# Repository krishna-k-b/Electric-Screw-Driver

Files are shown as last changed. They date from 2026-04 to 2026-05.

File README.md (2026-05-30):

# Electric-Screw-Driver
Attempt to make a Torque-sensing DC screwdriver using motor current feedback for real-time torque estimation and inertia aware control

# DRV8701 + RP2040 Brushed DC Screwdriver

Firmware for a handheld brushed-DC screwdriver using a Raspberry Pi Pico (RP2040) and a DRV8701 gate driver in PH/EN mode with an external N-MOSFET H-bridge. Features closed-loop current sensing, configurable torque limiting, soft-start, dithering, and full serial telemetry over CMSIS-DAP / Picoprobe.

## Table of Contents

- [Hardware Overview](#hardware-overview)
- [Pin Map](#pin-map)
- [Current Sensing Circuit](#current-sensing-circuit)
- [Building](#building)
- [Flashing](#flashing)
- [Debug / Serial Interface](#debug--serial-interface)
- [Serial Commands](#serial-commands)
- [State Machine](#state-machine)
- [Torque Control](#torque-control)
- [LED Indicator](#led-indicator)
- [Configuration Reference](#configuration-reference)

---

## Hardware Overview

| Component | Part |
|---|---|
| MCU | Raspberry Pi Pico (RP2040) |
| Gate driver | Texas Instruments DRV8701 |
| Bridge topology | External N-MOSFET H-bridge (PH/EN mode) |
| Current sense | 5 mΩ shunt + DRV8701 SO pin + resistor divider |
| Trigger | Two momentary buttons — CW (GP13) and CCW (GP12) |
| Speed control | Fixed 100 % duty with soft-start ramp (no pot fitted) |

---

## Pin Map

| GPIO | Direction | Function |
|---|---|---|
| GP0 | OUT | UART0 TX → Picoprobe GP5 |
| GP1 | IN | UART0 RX → Picoprobe GP4 |
| GP12 | IN (pull-up) | Button CCW — active LOW |
| GP13 | IN (pull-up) | Button CW — active LOW |
| GP16 | OUT (PWM) | DRV8701 EN/PWM — 20 kHz |
| GP17 | OUT | DRV8701 PH/DIR — HIGH = CW |
| GP18 | OUT | DRV8701 nSLEEP — LOW = Hi-Z |
| GP19 | IN (pull-up) | DRV8701 nFAULT — open-drain active LOW |
| GP26 | AIN | ADC CH0 — SO current sense |
| GP27 | AIN | ADC CH1 — pot (wired, reading disabled) |
| GP25 | OUT | Onboard LED |

---

## Current Sensing Circuit

The DRV8701 SO pin outputs a voltage proportional to motor current. A resistor divider scales it to the RP2040's 3.3 V ADC range.

```
SO pin ──┬── 10 kΩ ──── 3.3 V
         │
         ├── GP26 (ADC CH0)
         │
        20 kΩ
         │
        GND
```

| Parameter | Value |
|---|---|
| Divider ratio (V_ADC / V_SO) | 0.6667 (20 / 30) |
| Amplifier gain | 20 V/V |
| Sense resistor | 5 mΩ |
| SO offset voltage | 50 mV |

**Current calculation** (per loop tick):

```
V_SO_real      = V_ADC / 0.6667
V_SO_on_phase  = V_SO_real / duty_fraction      ← duty-cycle compensation
V_across_amp   = V_SO_on_phase − 0.050 V
I              = V_across_amp / (20 × 0.005)
```

Readings are frozen when duty < 10 % to avoid noise during near-zero on-time. A first-order IIR filter (α = 0.25) smooths the result.

---

## Building

### Prerequisites

- [Raspberry Pi Pico SDK](https://github.com/raspberrypi/pico-sdk) (≥ 1.5)
- CMake ≥ 3.13
- `arm-none-eabi-gcc`

### CMakeLists.txt fragment

```cmake
add_executable(screwdriver DRV_ESD.cpp)

target_link_libraries(screwdriver PRIVATE
    pico_stdlib
    hardware_pwm
    hardware_adc
    hardware_gpio
    hardware_uart
    hardware_watchdog
    hardware_clocks
)

pico_enable_stdio_uart(screwdriver 1)
pico_enable_stdio_usb(screwdriver 0)
pico_add_extra_outputs(screwdriver)
```

### Build

```bash
mkdir build && cd build
cmake ..
make -j4
```

This produces `DRV_ESD.uf2`.

---

## Flashing

Hold the **BOOTSEL** button on the Pico while plugging in USB. Drag `DRV_ESD.uf2` onto the `RPI-RP2` mass-storage device that appears. The board resets and starts running immediately.
Above is for flashing without debugger, i usually flash the .elf file through debugger. Read Pico Debug documentation should you wish to flash using a debugger.

---

## Debug / Serial Interface

Connect a second Pico running [Picoprobe](https://github.com/raspberrypi/picoprobe) firmware:

| Target | Picoprobe |
|---|---|
| GP0 (TX) | GP5 |
| GP1 (RX) | GP4 |
| GND | GND |

Open the CDC serial port at **921 600 baud, 8N1**. All log lines are prefixed with a millisecond timestamp:

```
[T+   1234 ms] STATE  IDLE -> STARTING  [trigger engaged]
[T+   1284 ms] TELEM  STARTING  dir=CW   I= 0.12A ...
```

---

## Serial Commands

Send commands surrounded by angle brackets, e.g. `<help>`.

| Command | Description |
|---|---|
| `<help>` | Full status dump + command list |
| `<status>` | Same as `<help>` |
| `<cw>` | Start motor CW (latched until `<stop>` or torque trip) |
| `<ccw>` | Start motor CCW (latched until `<stop>` or torque trip) |
| `<stop>` | Clear any serial motor request |
| `<ith X.X>` | Set current threshold in amps, e.g. `<ith 4.5>` |

Serial requests behave identically to physical button presses. `<cw>` and `<ccw>` are only accepted from **IDLE** or **STOPPED**; they are ignored and logged otherwise.

---

## State Machine

```
         ┌──────────────────────────────────────────────────────────────────┐
         │  nFAULT asserted (any time)                                      ▼
  BOOT ──► IDLE ──trigger──► STARTING ──ramp done──► RUNNING               FAULT
           ▲                    │                      │  │                   │
           │              early release             trip │  I > 80% Ith       │ nFAULT clear
           │                    │                        ▼  ▼              + holdoff
           │                    └───────────────► STOPPING ◄── DITHERING      │
           │                                          │             │          │
           │                                    cooldown done       │ I < 60% Ith
           │                                          ▼             │
           └──────────────── trigger released ── STOPPED            └──► RUNNING
```

| State | Description |
|---|---|
| `BOOT` | One-shot init, transitions immediately to `IDLE` |
| `IDLE` | Waiting for trigger; bridge is in sleep / Hi-Z |
| `STARTING` | 200 ms linear duty ramp from 0 → 100 % |
| `RUNNING` | Full duty, monitoring current |
| `DITHERING` | Near threshold — duty modulated to hold current just below limit |
| `STOPPING` | EN = 0 (brake), 300 ms cooldown before sleep |
| `STOPPED` | Bridge asleep; waiting for trigger release before next run |
| `FAULT` | nFAULT asserted by DRV8701; motor braked, LED solid ON |

**Trigger logic** — either the physical button *or* a latched serial request counts as a trigger. If both CW and CCW are simultaneously active (buttons or serial), no motion occurs until the conflict resolves.

---

## Torque Control

Three layered mechanisms protect the motor and workpiece:

### 1. Threshold current trip (sustained overcurrent)

The firmware trips if `I_filtered ≥ I_threshold` persists for **5 consecutive milliseconds**. Default threshold is **5.0 A**; adjustable at runtime with `<ith X.X>` (range 2–10 A). On trip, the motor brakes and the state machine enters `STOPPING`.

### 2. Hard limit

If filtered current reaches **14 A** at any time — including during soft-start — the motor brakes immediately regardless of threshold setting. This protects the FETs from thermal runaway.

### 3. Rapid dI/dt (stall detection)

A ring buffer of the last 8 current samples is compared oldest-to-newest. If the window rise exceeds **4 A**, the motor trips. This catches stalls that happen before sustained overcurrent would fire.

### Dithering (soft current limiting)

Between **80 %** and **100 %** of the threshold current the firmware enters `DITHERING` and scales the duty cycle proportionally down to a minimum of **30 %**, holding torque steady rather than hard-tripping. The motor returns to `RUNNING` if current drops back below **60 %** of threshold.

---

## LED Indicator

| LED state | Meaning |
|---|---|
| Off | Idle / stopped / boot |
| Blinking (0.5 s period) | Motor energised (STARTING, RUNNING, DITHERING) |
| Solid ON | FAULT |

---

## Configuration Reference

All compile-time tunables are `constexpr` near the top of `DRV_ESD.cpp`.

| Symbol | Default | Description |
|---|---|---|
| `I_THRESHOLD_DEFAULT_A` | 5.0 A | Starting current threshold (no pot) |
| `I_THRESHOLD_MIN_A` | 2.0 A | Lower bound for `<ith>` command |
| `I_THRESHOLD_MAX_A` | 10.0 A | Upper bound for `<ith>` command |
| `I_HARD_LIMIT_A` | 14.0 A | Unconditional FET protection limit |
| `SOFT_START_MS` | 200 ms | Duty ramp duration on trigger press |
| `COOLDOWN_MS` | 300 ms | Brake hold time before bridge sleeps |
| `FAULT_HOLDOFF_MS` | 150 ms | Debounce after nFAULT clears |
| `OVERCURRENT_CONFIRM_MS` | 5 ms | Sustained OC window before trip |
| `DI_DT_TRIP_A_PER_WIN` | 4.0 A | dI/dt trip threshold over 8-sample window |
| `DITHER_START_FRAC` | 0.80 | Dither zone entry — fraction of I_threshold |
| `DITHER_MIN_DUTY_FRAC` | 0.30 | Minimum PWM duty while dithering |
| `IIR_ALPHA` | 0.25 | Current filter coefficient (higher = faster) |
| `PWM_WRAP` | 6249 | PWM counter wrap → 20 kHz at 125 MHz |
| `LOOP_PERIOD_US` | 5000 µs | Main loop period (200 Hz) |
| `WATCHDOG_TIMEOUT_MS` | 250 ms | Watchdog reset if loop stalls |
| `UART_BAUD` | 921 600 | Debug UART baud rate |

---

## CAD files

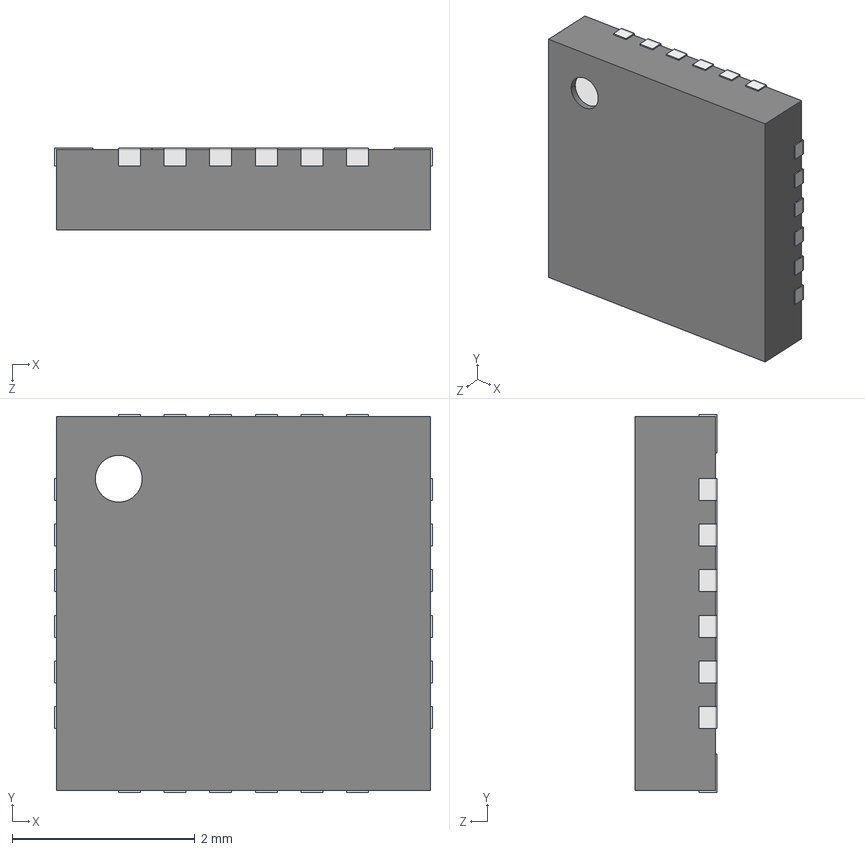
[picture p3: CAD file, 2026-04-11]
DRV8701-ESD_PCB/ul_DRV8701ERGER/qfn-24-1.snapshot.1/QFN 24.STEP
4.14 x 4.14 x 0.9 mm
Open_CASCADE_STEP_translator_6.8_11.2.1.step_Varsay考an
Open_CASCADE_STEP_translator_6.8_11.4.1.step_Varsay考an x 24
Open_CASCADE_STEP_translator_6.8_11.1.step_Varsay考an
Thermal_Shape.step_Varsay考an

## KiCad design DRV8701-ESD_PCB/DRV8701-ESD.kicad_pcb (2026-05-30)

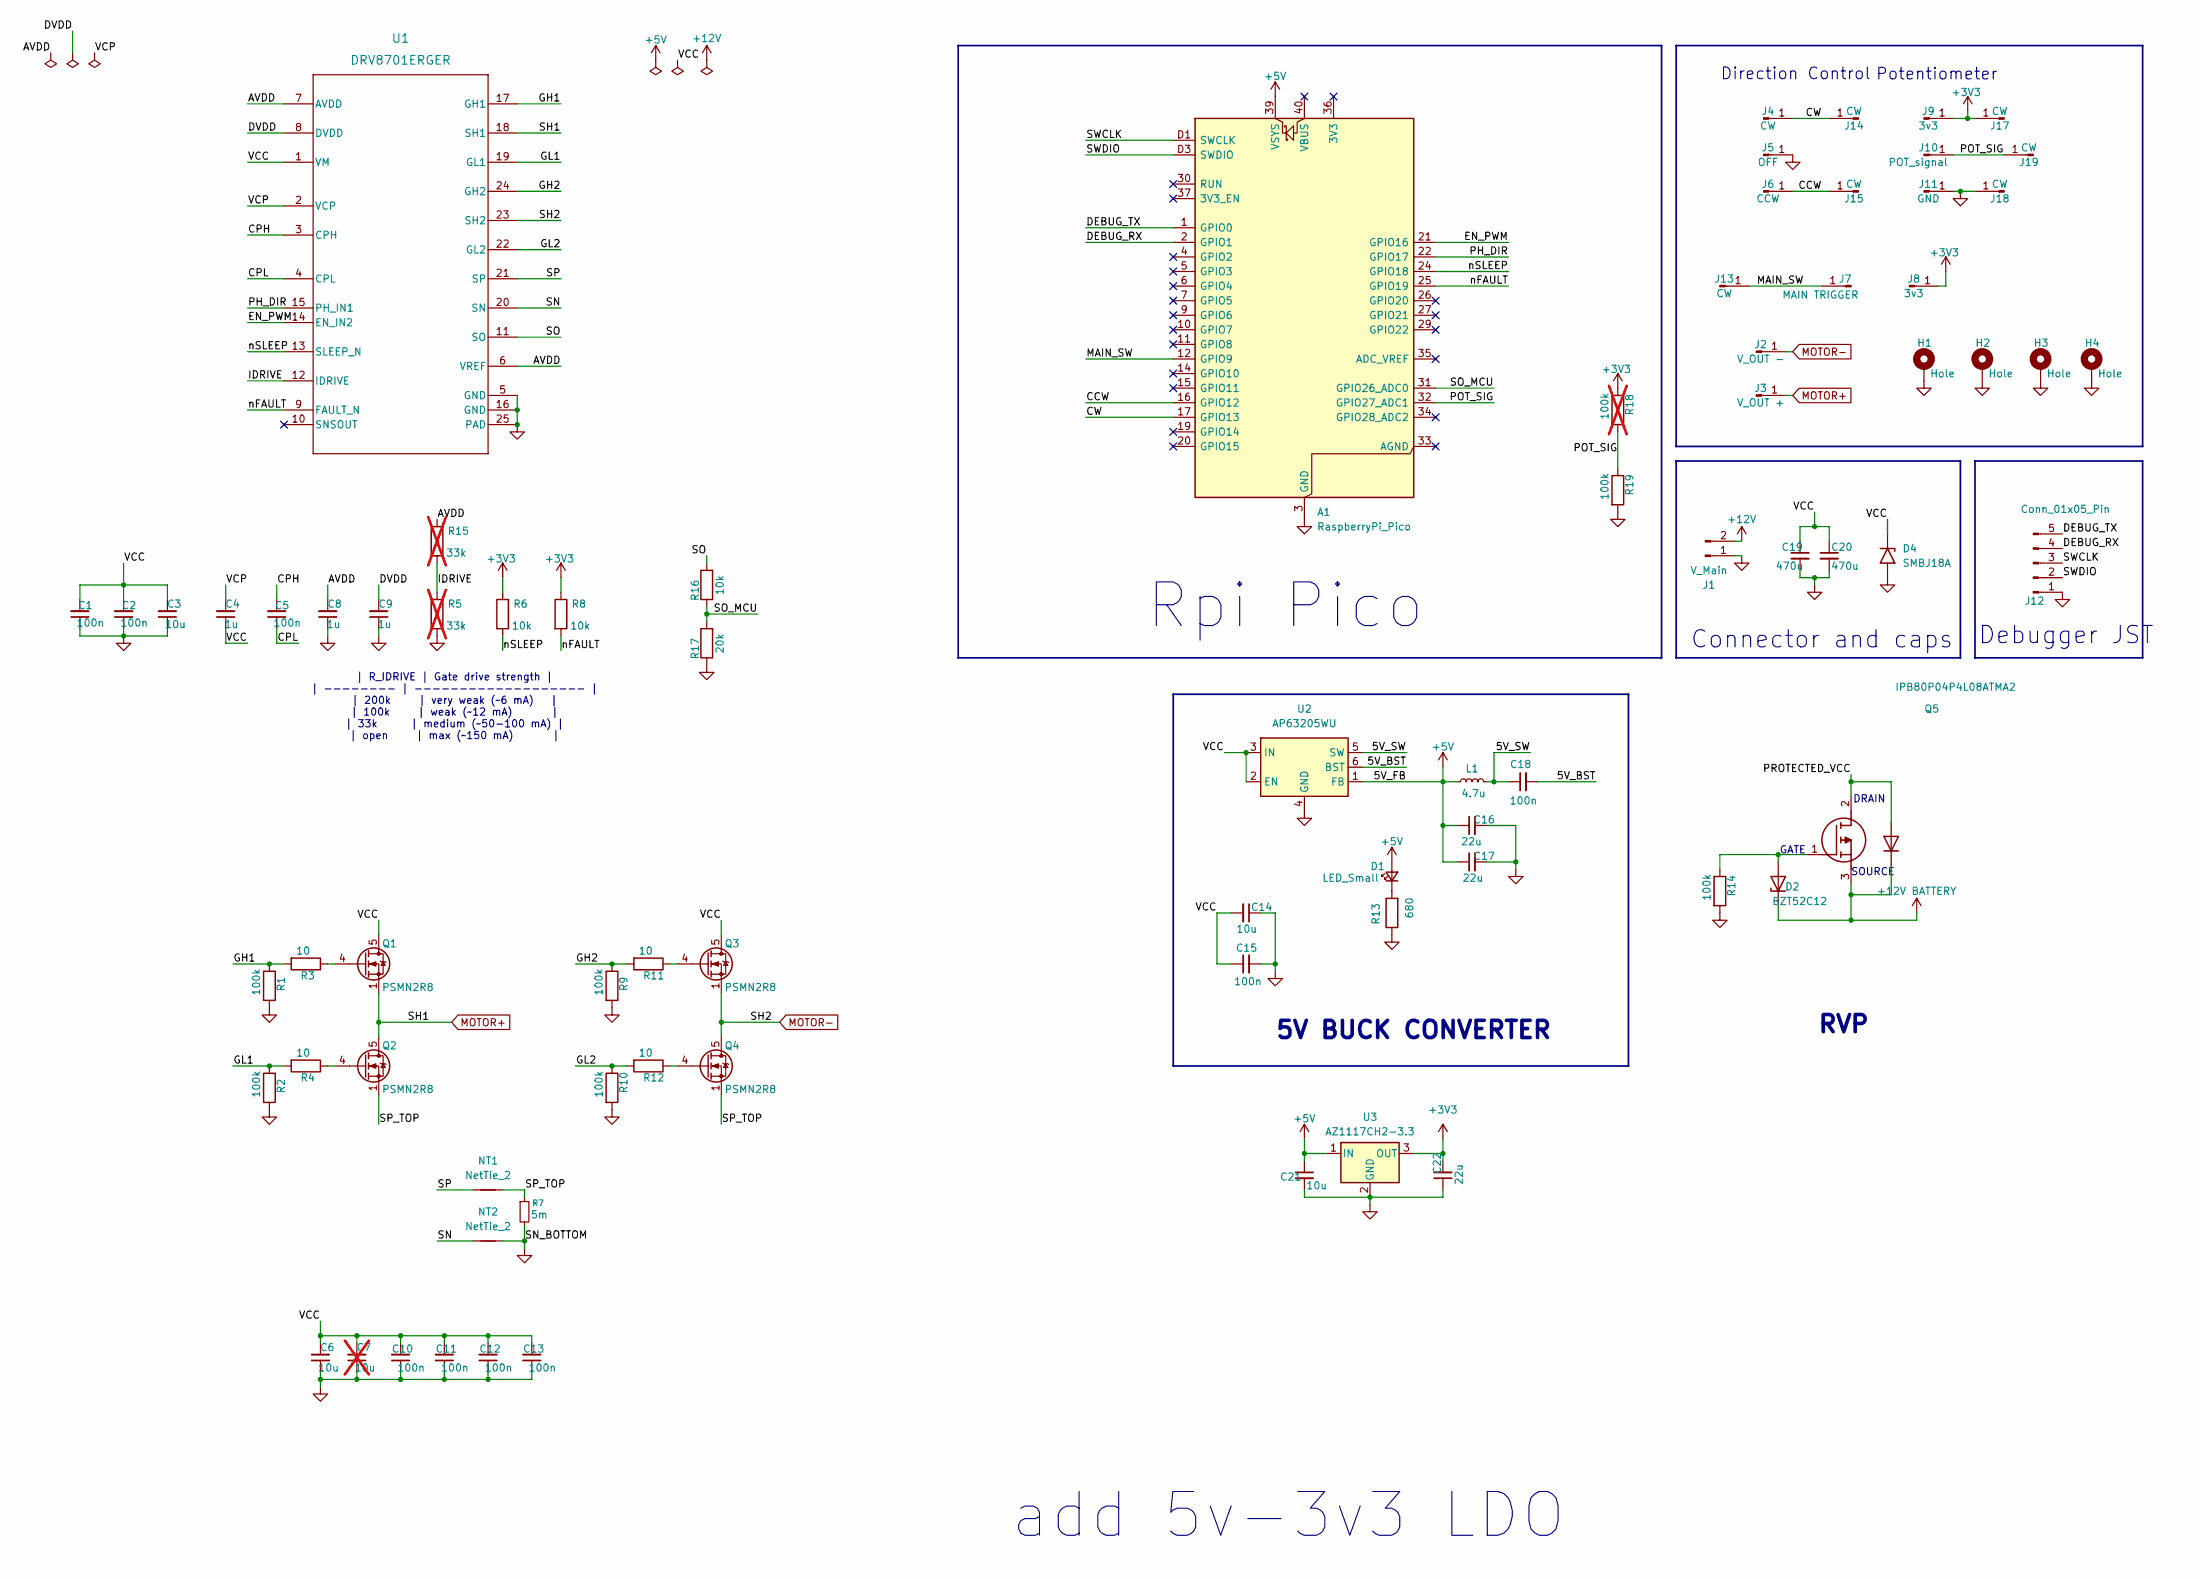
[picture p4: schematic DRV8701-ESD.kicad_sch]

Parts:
A1: RaspberryPi_Pico; RaspberryPi_Pico_SMD_HandSolder
C1, C2, C5, C10, C11, C12, C13, C15, C18: 100n; C_0603_1608Metric_Pad1.08x0.95mm_HandSolder
C3, C6, C14, C21: 10u; C_1206_3216Metric_Pad1.33x1.80mm_HandSolder; LCSC C77096
C4, C8, C9: 1u; C_0805_2012Metric_Pad1.18x1.45mm_HandSolder
C7: 10u; C_1206_3216Metric_Pad1.33x1.80mm_HandSolder; LCSC C77096; not fitted
C16, C17, C22: 22u; C_1210_3225Metric_Pad1.33x2.70mm_HandSolder; LCSC C86816
C19, C20: 470u; C_Radial_D10.0mm_H20.0mm_P5.00mm
D1: LED_Small; LED_0603_1608Metric_Pad1.05x0.95mm_HandSolder
D2: BZT52C12; D_SOD-123F
D4: SMBJ18A; D_SMA-SMB_Universal_Handsoldering
H1, H2, H3, H4: Hole; MountingHole_3.2mm_M3_Pad
J1: V_Main; AMASS_XT60-F_1x02_P7.20mm_Vertical
J2: V_OUT -; Solder_Pad_10x10mm_withVias
J3: V_OUT +; Solder_Pad_10x10mm_withVias
J4: CW; PinHeader_1x01_P2.54mm_Vertical
J5: OFF; PinHeader_1x01_P2.54mm_Vertical
J6: CCW; PinHeader_1x01_P2.54mm_Vertical
J7: MAIN TRIGGER; PinHeader_1x01_P2.54mm_Vertical
J8, J9: 3v3; PinHeader_1x01_P2.54mm_Vertical
J10: POT_signal; PinHeader_1x01_P2.54mm_Vertical
J11: GND; PinHeader_1x01_P2.54mm_Vertical
J12: Conn_01x05_Pin; Molex_PicoBlade_53047-0510_1x05_P1.25mm_Vertical
J13, J14, J15, J17, J18, J19: CW; 3.5x3.5_Solder_Pads
L1: 4.7u; L_SMD_6mmx6mm
NT1, NT2: NetTie_2; NetTie-2_SMD_Pad0.2mm
Q1, Q2, Q3, Q4: PSMN2R8; LFPAK56
Q5: IPB80P04P4L08ATMA2; TO-263-2
R1, R2, R9, R10, R14, R19: 100k; R_0603_1608Metric_Pad0.98x0.95mm_HandSolder
R3, R4, R11, R12: 10; R_0603_1608Metric_Pad0.98x0.95mm_HandSolder
R5, R15: 33k; R_0603_1608Metric_Pad0.98x0.95mm_HandSolder; not fitted
R6, R8, R16: 10k; R_0603_1608Metric_Pad0.98x0.95mm_HandSolder
R7: 5m; R_2512_6332Metric_Pad1.40x3.35mm_HandSolder
R13: 680; C_0603_1608Metric_Pad1.08x0.95mm_HandSolder
R17: 20k; R_0603_1608Metric_Pad0.98x0.95mm_HandSolder
R18: 100k; R_0603_1608Metric_Pad0.98x0.95mm_HandSolder; not fitted
U1: DRV8701ERGER; RGE0024F_NV
U2: AP63205WU; TSOT-23-6
U3: AZ1117CH2-3.3; SOT-223-3_TabPin2

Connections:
+3V3: C22.2, J8.1, J9.1, J17.1, R6.1, R8.1, R18.1, U3.3 (OUT)
+5V: A1.39 (VSYS), C16.1, C17.1, C21.1, D1.2 (A), L1.1, U2.1 (FB), U3.1 (IN)
/5V_BST: C18.2, U2.6 (BST)
/5V_SW: C18.1, L1.2, U2.5 (SW)
/AVDD: C8.2, R15.1, U1.6 (VREF), U1.7 (AVDD)
/CCW: A1.16 (GPIO12), J6.1, J15.1
/CPH: C5.2, U1.3 (CPH)
/CPL: C5.1, U1.4 (CPL)
/CW: A1.17 (GPIO13), J4.1, J14.1
/DEBUG_RX: A1.2 (GPIO1), J12.4
/DEBUG_TX: A1.1 (GPIO0), J12.5
/DVDD: C9.2, U1.8 (DVDD)
/EN_PWM: A1.21 (GPIO16), U1.14 (EN_IN2)
/GH1: R1.1, R3.2, U1.17 (GH1)
/GH2: R9.1, R11.2, U1.24 (GH2)
/GL1: R2.1, R4.2, U1.19 (GL1)
/GL2: R10.1, R12.2, U1.22 (GL2)
/IDRIVE: R5.1, R15.2, U1.12 (IDRIVE)
/MAIN_SW: A1.12 (GPIO9), J7.1, J13.1
/PH_DIR: A1.22 (GPIO17), U1.15 (PH_IN1)
/POT_SIG: A1.32 (GPIO27_ADC1), J10.1, J19.1, R18.2, R19.1
/SN: NT2.1, U1.20 (SN)
/SO: R16.2, U1.11 (SO)
/SO_MCU: A1.31 (GPIO26_ADC0), R16.1, R17.2
/SP: NT1.1, U1.21 (SP)
/SP_TOP: NT1.2, Q2.1 (S), Q2.2 (S), Q2.3 (S), Q4.1 (S), Q4.2 (S), Q4.3 (S), R7.1
/SWCLK: A1.D1 (SWCLK), J12.3
/SWDIO: A1.D3 (SWDIO), J12.2
/VCP: C4.2, U1.2 (VCP)
/nFAULT: A1.25 (GPIO19), R8.2, U1.9 (FAULT_N)
/nSLEEP: A1.24 (GPIO18), R6.2, U1.13 (SLEEP_N)
GND: A1.3 (GND), A1.8 (GND), A1.13 (GND), A1.18 (GND), A1.23 (GND), A1.28 (GND), A1.38 (GND), A1.D2 (GND), C1.1, C2.1, C3.1, C6.1, C7.1, C8.1, C9.1, C10.1, C11.1, C12.1, C13.1, C14.1, C15.2, C16.2, C17.2, C19.2, C20.2, C21.2, C22.1, D4.2 (A2), H1.1, H2.1, H3.1, H4.1, J1.1, J5.1, J11.1, J12.1, J18.1, NT2.2, R1.2, R2.2, R5.2, R7.2, R9.2, R10.2, R13.1, R14.2, R17.1, R19.2, U1.5 (GND), U1.16 (GND), U1.25 (PAD), U2.4 (GND), U3.2 (GND)
MOTOR+: J3.1, Q1.1 (S), Q1.2 (S), Q1.3 (S), Q2.5 (D), U1.18 (SH1)
MOTOR-: J2.1, Q3.1 (S), Q3.2 (S), Q3.3 (S), Q4.5 (D), U1.23 (SH2)
unnamed: D1.1 (K), R13.2
unnamed: D2.2 (A), Q5.1 (G), R14.1
unnamed: Q1.4 (G), R3.1
unnamed: Q2.4 (G), R4.1
unnamed: Q3.4 (G), R11.1
unnamed: Q4.4 (G), R12.1

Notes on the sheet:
Potentiometer
5V BUCK CONVERTER
Debugger JST
DRAIN
Direction Control
GATE
| R_IDRIVE | Gate drive strength | | -------- | ------------------- | | 200k | very weak (~6 mA) | | 100k | weak (~12 mA) | | 33k | medium (~50-100 mA) | | open | max (~150 mA) |
SOURCE
add 5v-3v3 LDO
Rpi Pico
RVP
Connector and caps

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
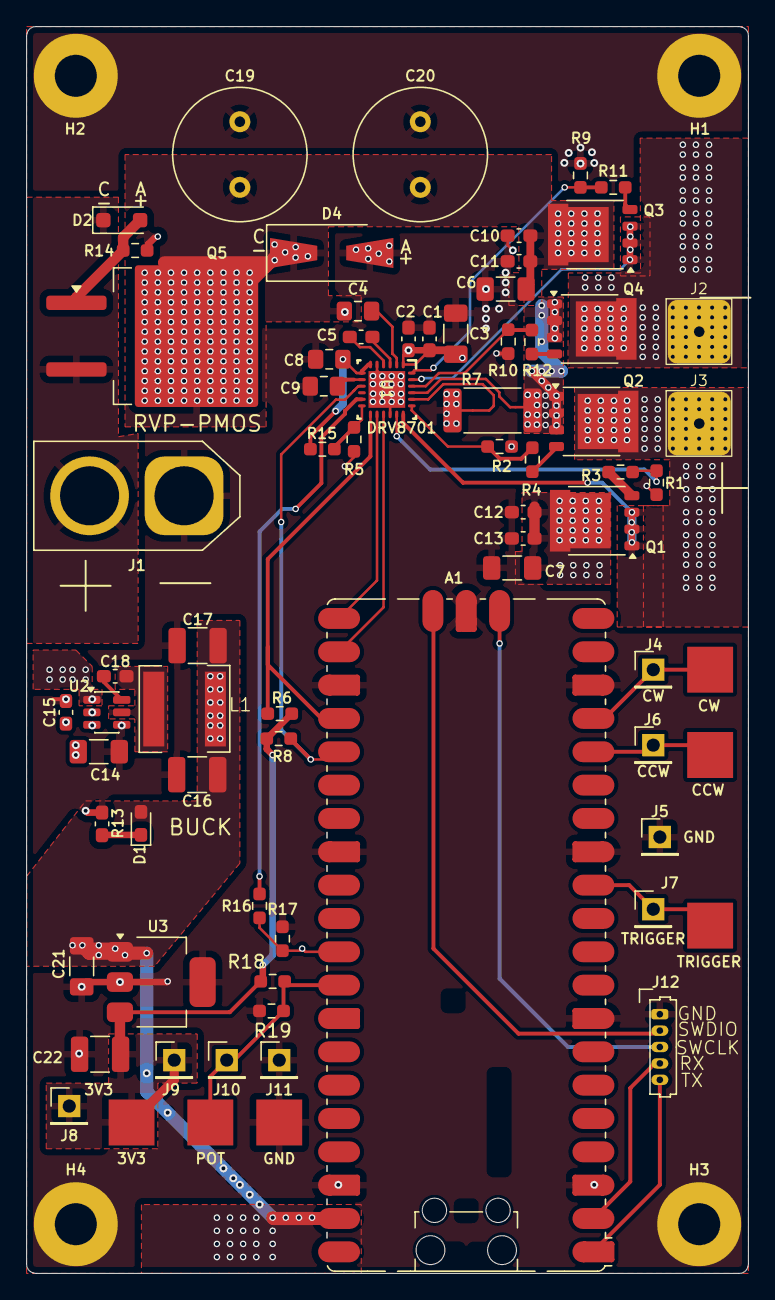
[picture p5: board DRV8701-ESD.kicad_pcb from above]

Board: 4 copper layers, 55.0 x 95.0 mm, 78 parts (0 on the bottom side), 42 nets.

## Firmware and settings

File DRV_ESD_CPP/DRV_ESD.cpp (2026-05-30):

/* =========================================================================
 *  DRV8701 + RP2040 Brushed DC Screwdriver Firmware
 *  -------------------------------------------------
 *  Toolchain : Pico SDK (C/C++), no Arduino libraries.
 *  MCU       : Raspberry Pi Pico (RP2040)
 *  Driver    : DRV8701 in PH/EN mode with external N-MOSFET H-bridge
 *
 *  CMSIS-DAP / Picoprobe serial debug
 *  ------------------------------------
 *  Connect a second Pico running Picoprobe firmware:
 *    Target GP0 (TX) -> Picoprobe GP5
 *    Target GP1 (RX) -> Picoprobe GP4
 *  Open the CDC serial port at 115200 baud in your IDE / terminal.
 *  All events are timestamped [T+xxxxx ms].
 *
 *  SO divider: 10 k (top) + 20 k (bottom)
 *    V_adc = V_SO * 20/(10+20) = 0.6667  =>  SO_DIVIDER_RATIO = 0.6667
 *
 *  TRIGGER LOGIC (no separate trigger button):
 *    - CW  button (GP13, active-LOW, internal pull-up) = run CW  while held
 *    - CCW button (GP12, active-LOW, internal pull-up) = run CCW while held
 *    - Both pressed simultaneously => no motion
 *    - Motor also controllable via serial commands (see <help>)
 *
 *  POT: not connected. Threshold defaults to I_THRESHOLD_DEFAULT_A.
 *       Use <ith X.X> serial command to change at runtime.
 *
 *  LED (GP25 onboard):
 *    OFF   = idle / stopped / boot
 *    BLINK = motor energised (STARTING / RUNNING / DITHERING) - 0.5 s period
 *    ON    = FAULT state
 *
 *  Serial commands  (send inside angle brackets, e.g.  <help> ):
 *    <help>      full status dump + command list
 *    <status>    same as <help>
 *    <cw>        start motor CW  (latched until <stop> or trip)
 *    <ccw>       start motor CCW (latched until <stop> or trip)
 *    <stop>      release serial motor request
 *    <ith X.X>   set current threshold in amps  (e.g. <ith 4.5>)
 *
 *  Build (CMakeLists.txt fragment)
 *    add_executable(screwdriver screwdriver_firmware.cpp)
 *    target_link_libraries(screwdriver PRIVATE
 *        pico_stdlib hardware_pwm hardware_adc hardware_gpio
 *        hardware_uart hardware_watchdog hardware_clocks)
 *    pico_enable_stdio_uart(screwdriver 1)
 *    pico_enable_stdio_usb(screwdriver 0)
 *    pico_add_extra_outputs(screwdriver)
 * ========================================================================= */

#include "hardware/adc.h"
#include "hardware/clocks.h"
#include "hardware/gpio.h"
#include "hardware/pwm.h"
#include "hardware/uart.h"
#include "hardware/watchdog.h"
#include "pico/stdlib.h"
#include "pico/time.h"
#include <cmath>
#include <cstdint>
#include <cstdio>
#include <cstring>
#include <stdio.h>
#include <string.h>

/* =========================================================================
 *  CONFIG -- adjust to match your hardware
 * ========================================================================= */

/* ---- Pin map ---- */
static constexpr uint PIN_UART_TX = 0;
static constexpr uint PIN_UART_RX = 1;
/* GP9 (main trigger) intentionally unused -- CW/CCW are the triggers */
static constexpr uint PIN_BTN_CCW = 12;
static constexpr uint PIN_BTN_CW  = 13;
static constexpr uint PIN_EN_PWM  = 16;
static constexpr uint PIN_PH_DIR  = 17;
static constexpr uint PIN_NSLEEP  = 18;
static constexpr uint PIN_NFAULT  = 19;
static constexpr uint PIN_ADC_SO  = 26;
static constexpr uint PIN_ADC_POT = 27; /* wired but reading ignored (POT_CONNECTED=false) */
static constexpr uint ADC_CH_SO   = 0;
static constexpr uint ADC_CH_POT  = 1;
static constexpr uint PIN_LED     = 25; /* onboard LED */

/* ---- Button polarity ---- */
static constexpr int BTN_PRESSED = 0; /* active-LOW with pull-up */

/* ---- Pot / threshold ---- */
static constexpr bool  POT_CONNECTED          = false;
static constexpr float I_THRESHOLD_DEFAULT_A  = 5.0f; /* used when POT_CONNECTED=false */

/* ---- Analog ---- */
static constexpr float ADC_VREF_V       = 3.3f;
static constexpr float ADC_COUNTS       = 4096.0f;
static constexpr float SO_DIVIDER_RATIO = 0.6667f; /* 10k top + 20k bottom */
static constexpr float DRV_AMP_GAIN     = 20.0f;  /* V/V */
static constexpr float R_SENSE_OHM      = 0.005f; /* 5 mohm */
static constexpr float SO_OFFSET_V      = 0.050f; /* V_OFF typical (DS tbl 6.5) */

/* ---- PWM ---- */
/* 125 MHz / (1 * 6250) = 20 kHz */
static constexpr uint16_t PWM_WRAP    = 6249;
static constexpr float    PWM_CLKDIV  = 1.0f;
static constexpr uint16_t PWM_DUTY_MAX = PWM_WRAP;

/* ---- Torque limits ---- */
static constexpr float I_THRESHOLD_MIN_A  = 2.0f;
static constexpr float I_THRESHOLD_MAX_A  = 10.0f;
static constexpr float I_HARD_LIMIT_A     = 14.0f;
static constexpr float DUTY_FLOOR_FOR_I_EST = 0.10f;

/* ---- Timing ---- */
static constexpr uint32_t LOOP_PERIOD_US      = 5000;
static constexpr uint32_t SOFT_START_MS       = 200;
static constexpr uint32_t COOLDOWN_MS         = 300;
static constexpr uint32_t DEBOUNCE_MS         = 25;
static constexpr uint32_t FAULT_HOLDOFF_MS    = 150;
static constexpr uint32_t WAKE_DELAY_MS       = 2;
static constexpr uint32_t WATCHDOG_TIMEOUT_MS = 250;

/* ---- Logging ---- */
static constexpr uint32_t LOG_PERIOD_ACTIVE_MS = 50;  /* 20 Hz while running */
static constexpr uint32_t LOG_PERIOD_IDLE_MS   = 500; /* 2 Hz at idle/stopped */

/* ---- LED ---- */
static constexpr uint32_t LED_BLINK_HALF_MS = 250; /* on 250ms, off 250ms => 0.5s period */

/* ---- Filtering & detection ---- */
static constexpr float IIR_ALPHA            = 0.25f;
static constexpr int   DI_DT_HISTORY        = 8;
static constexpr float DI_DT_TRIP_A_PER_WIN = 4.0f;
static constexpr float DITHER_START_FRAC    = 0.80f;
static constexpr float DITHER_MIN_DUTY_FRAC = 0.30f;
static constexpr int   OVERCURRENT_CONFIRM_MS = 5;

/* ---- UART ---- */
static constexpr uint32_t UART_BAUD = 921600
;
#define UART_ID uart0

/* =========================================================================
 *  TYPES
 * ========================================================================= */

enum class State : uint8_t {
  BOOT,
  IDLE,
  STARTING,
  RUNNING,
  DITHERING,
  STOPPING,
  STOPPED,
  FAULT
};

enum class Direction : uint8_t { CW = 1, CCW = 0 };

struct Button {
  uint  pin;
  bool  stable;
  bool  last_raw;
  absolute_time_t last_change;
  bool  edge_pressed;
  bool  edge_released;
};

struct Context {
  State     state;
  Direction dir;
  uint      pwm_slice;
  uint      pwm_chan;

  Button sw_cw;
  Button sw_ccw;

  /* Serial virtual buttons (latched by <cw>/<ccw>, cleared by <stop>/trip) */
  bool serial_cw_req;
  bool serial_ccw_req;

  /* Conflict tracking (both buttons simultaneously) */
  bool conflict_logged;

  /* Analog */
  float i_filt_a;
  float i_raw_a;
  float i_threshold_a; /* set from pot (if connected) or serial <ith> command */
  float pot_v;
  float so_v;
  float duty_frac;

  /* dI/dt history */
  float i_hist[DI_DT_HISTORY];
  int   i_hist_idx;
  float di_dt_last;

  /* Trip confirmations */
  int overcurrent_ms;
  int fault_holdoff_ms;

  /* PWM control */
  uint16_t duty_target;
  uint16_t duty_current;
  absolute_time_t soft_start_began;

  /* Cooldown */
  absolute_time_t cooldown_began;

  /* Logging */
  absolute_time_t last_log;
  absolute_time_t boot_time;
  uint16_t        last_logged_duty;

  /* Hardware state tracking (avoid repeated log spam) */
  bool nsleep_out;  /* current logical state of nSLEEP pin */

  /* Fault */
  bool        nfault_asserted;
  const char *fault_reason;

  /* Serial command buffer */
  char serial_buf[80];
  int  serial_buf_len;
  bool serial_in_cmd;
};

static Context g{};

/* =========================================================================
 *  TIMESTAMP + LOG MACRO
 * ========================================================================= */

static uint32_t ts_ms(void) {
  return (uint32_t)(absolute_time_diff_us(g.boot_time, get_absolute_time()) /
                    1000);
}

#define LOG(fmt, ...) printf("[T+%7u ms] " fmt "\n", ts_ms(), ##__VA_ARGS__)

/* =========================================================================
 *  LOW-LEVEL HELPERS
 * ========================================================================= */

static inline float clampf(float v, float lo, float hi) {
  return v < lo ? lo : (v > hi ? hi : v);
}

/* =========================================================================
 *  TRIGGER LOGIC
 *  Returns true if the currently active direction's trigger is still held.
 *  Physical button OR latched serial request counts.
 * ========================================================================= */

static bool want_cw(void)  { return g.sw_cw.stable  || g.serial_cw_req;  }
static bool want_ccw(void) { return g.sw_ccw.stable  || g.serial_ccw_req; }

static bool trigger_held(void) {
  if (g.dir == Direction::CW)  return want_cw();
  if (g.dir == Direction::CCW) return want_ccw();
  return false;
}

/* =========================================================================
 *  PERIPHERAL INIT
 * ========================================================================= */

static void uart_init_debug(void) {
  uart_init(UART_ID, UART_BAUD);
  gpio_set_function(PIN_UART_TX, GPIO_FUNC_UART);
  gpio_set_function(PIN_UART_RX, GPIO_FUNC_UART);
  uart_set_format(UART_ID, 8, 1, UART_PARITY_NONE);
  uart_set_fifo_enabled(UART_ID, true);
  stdio_init_all();
}

static void gpio_init_all(void) {
  /* nSLEEP -- output, force LOW (sleep / Hi-Z) before we are ready */
  gpio_init(PIN_NSLEEP);
  gpio_put(PIN_NSLEEP, 0);
  gpio_set_dir(PIN_NSLEEP, GPIO_OUT);
  g.nsleep_out = false;

  /* PH direction -- output, default CW (HIGH) */
  gpio_init(PIN_PH_DIR);
  gpio_put(PIN_PH_DIR, 1);
  gpio_set_dir(PIN_PH_DIR, GPIO_OUT);

  /* nFAULT -- input with internal + external pull-up */
  gpio_init(PIN_NFAULT);
  gpio_set_dir(PIN_NFAULT, GPIO_IN);
  gpio_pull_up(PIN_NFAULT);

  /* CW / CCW buttons -- input, internal pull-up, active-LOW */
  const uint btns[] = {PIN_BTN_CW, PIN_BTN_CCW};
  for (uint p : btns) {
    gpio_init(p);
    gpio_set_dir(p, GPIO_IN);
    gpio_pull_up(p);
  }

  /* Onboard LED */
  gpio_init(PIN_LED);
  gpio_set_dir(PIN_LED, GPIO_OUT);
  gpio_put(PIN_LED, 0);
}

static void pwm_init_motor(void) {
  gpio_set_function(PIN_EN_PWM, GPIO_FUNC_PWM);
  g.pwm_slice = pwm_gpio_to_slice_num(PIN_EN_PWM);
  g.pwm_chan  = pwm_gpio_to_channel(PIN_EN_PWM);

  pwm_config cfg = pwm_get_default_config();
  pwm_config_set_wrap(&cfg, PWM_WRAP);
  pwm_config_set_clkdiv(&cfg, PWM_CLKDIV);
  pwm_init(g.pwm_slice, &cfg, false);

  pwm_set_chan_level(g.pwm_slice, g.pwm_chan, 0);
  pwm_set_enabled(g.pwm_slice, true);
}

static void adc_init_all(void) {
  adc_init();
  adc_gpio_init(PIN_ADC_SO);
  adc_gpio_init(PIN_ADC_POT);
}

/* =========================================================================
 *  ADC + CONVERSION
 * ========================================================================= */

static uint16_t adc_read_channel(uint ch) {
  adc_select_input(ch);
  uint32_t sum = 0;
  for (int i = 0; i < 4; ++i)
    sum += adc_read();
  return (uint16_t)(sum / 4);
}

static float adc_to_volts(uint16_t counts) {
  return ((float)counts / ADC_COUNTS) * ADC_VREF_V;
}

static float volts_to_current_a(float v_so_avg, float duty_frac) {
  if (duty_frac < DUTY_FLOOR_FOR_I_EST)
    return g.i_filt_a; /* freeze below floor duty */
  float v_so_real      = v_so_avg / SO_DIVIDER_RATIO;
  float v_so_during_on = v_so_real / duty_frac;
  float v_across_amp   = v_so_during_on - SO_OFFSET_V;
  if (v_across_amp < 0)
    v_across_amp = 0;
  return v_across_amp / (DRV_AMP_GAIN * R_SENSE_OHM);
}

static float pot_to_threshold_a(float v_pot) {
  float frac = clampf(v_pot / ADC_VREF_V, 0.0f, 1.0f);
  return I_THRESHOLD_MIN_A + frac * (I_THRESHOLD_MAX_A - I_THRESHOLD_MIN_A);
}

/* =========================================================================
 *  BUTTONS (debounced, edge detection)
 * ========================================================================= */

static void button_init(Button &b, uint pin) {
  b.pin           = pin;
  b.stable        = false;
  b.last_raw      = (gpio_get(pin) == BTN_PRESSED);
  b.last_change   = get_absolute_time();
  b.edge_pressed  = false;
  b.edge_released = false;
}

static void button_update(Button &b) {
  bool raw = (gpio_get(b.pin) == BTN_PRESSED);
  absolute_time_t now = get_absolute_time();

  if (raw != b.last_raw) {
    b.last_raw    = raw;
    b.last_change = now;
  }

  bool old_stable = b.stable;
  if (absolute_time_diff_us(b.last_change, now) >= (int64_t)DEBOUNCE_MS * 1000)
    b.stable = raw;

  b.edge_pressed  = (!old_stable && b.stable);
  b.edge_released = (old_stable && !b.stable);
}

/* =========================================================================
 *  MOTOR CONTROL PRIMITIVES
 *  -- LOG only when hardware state actually changes to avoid UART spam
 * ========================================================================= */

static void motor_set_duty(uint16_t duty) {
  if (duty > PWM_DUTY_MAX)
    duty = PWM_DUTY_MAX;
  g.duty_current = duty;
  pwm_set_chan_level(g.pwm_slice, g.pwm_chan, duty);
}

static void motor_set_direction(Direction d) {
  g.dir = d;
  gpio_put(PIN_PH_DIR, d == Direction::CW ? 1 : 0);
  LOG("DIR set -> %s (GP%u = %d)", d == Direction::CW ? "CW" : "CCW",
      PIN_PH_DIR, d == Direction::CW ? 1 : 0);
}

static void motor_brake(void) {
  /* EN=0, nSLEEP=1 → low-side slow decay = brake (DRV8701 Table 1) */
  motor_set_duty(0);
  if (!g.nsleep_out) {
    gpio_put(PIN_NSLEEP, 1);
    g.nsleep_out = true;
  }
  LOG("MOTOR brake  (EN=0, nSLEEP=1, low-side slow decay)");
}

static void motor_sleep(void) {
  motor_set_duty(0);
  if (g.nsleep_out) { /* only act + log if not already sleeping */
    gpio_put(PIN_NSLEEP, 0);
    g.nsleep_out = false;
    LOG("MOTOR sleep  (nSLEEP=0, bridge Hi-Z)");
  }
}

static void motor_wake(void) {
  motor_set_duty(0);
  gpio_put(PIN_NSLEEP, 1);
  g.nsleep_out = true;
  sleep_ms(WAKE_DELAY_MS); /* only at state transition, not in hot loop */
  LOG("MOTOR wake   (nSLEEP=1, t_WAKE %u ms done)", WAKE_DELAY_MS);
}

/* =========================================================================
 *  LED
 *  OFF   = idle/stopped/boot
 *  BLINK = motor active (STARTING/RUNNING/DITHERING)  0.5 s period
 *  ON    = FAULT
 * ========================================================================= */

static void led_update(void) {
  bool is_fault  = (g.state == State::FAULT);
  bool is_active = (g.state == State::STARTING ||
                    g.state == State::RUNNING   ||
                    g.state == State::DITHERING);

  if (is_fault) {
    gpio_put(PIN_LED, 1);
  } else if (is_active) {
    /* toggle every LED_BLINK_HALF_MS */
    bool on = ((ts_ms() / LED_BLINK_HALF_MS) & 1u) == 0;
    gpio_put(PIN_LED, on ? 1 : 0);
  } else {
    gpio_put(PIN_LED, 0);
  }
}

/* =========================================================================
 *  STATE NAMES
 * ========================================================================= */

static const char *state_name(State s) {
  switch (s) {
  case State::BOOT:      return "BOOT";
  case State::IDLE:      return "IDLE";
  case State::STARTING:  return "STARTING";
  case State::RUNNING:   return "RUNNING";
  case State::DITHERING: return "DITHERING";
  case State::STOPPING:  return "STOPPING";
  case State::STOPPED:   return "STOPPED";
  case State::FAULT:     return "FAULT";
  }
  return "?";
}

static void enter_state(State s, const char *reason) {
  if (s == g.state)
    return;
  LOG("STATE  %s -> %s  [%s]", state_name(g.state), state_name(s),
      reason ? reason : "");
  g.state            = s;
  g.last_logged_duty = 0xFFFFu; /* force first telem to log duty */
}

/* =========================================================================
 *  INPUT UPDATE
 * ========================================================================= */

static void update_inputs(void) {
  button_update(g.sw_cw);
  button_update(g.sw_ccw);

  /* Button edge events */
  if (g.sw_cw.edge_pressed)
    LOG("BTN CW  pressed  (GP%u pulled LOW)", PIN_BTN_CW);
  if (g.sw_cw.edge_released)
    LOG("BTN CW  released (GP%u HIGH)", PIN_BTN_CW);
  if (g.sw_ccw.edge_pressed)
    LOG("BTN CCW pressed  (GP%u pulled LOW)", PIN_BTN_CCW);
  if (g.sw_ccw.edge_released)
    LOG("BTN CCW released (GP%u HIGH)", PIN_BTN_CCW);

  /* nFAULT -- open-drain active-LOW */
  bool nf_now = (gpio_get(PIN_NFAULT) == 0);
  if (nf_now != g.nfault_asserted) {
    LOG("nFAULT %s (GP%u = %d)",
        nf_now ? "ASSERTED -- LOW  (DRV8701 fault!)" : "de-asserted -- HIGH (cleared)",
        PIN_NFAULT, nf_now ? 0 : 1);
  }
  g.nfault_asserted = nf_now;

  /* ADC */
  g.so_v = adc_to_volts(adc_read_channel(ADC_CH_SO));
  if (POT_CONNECTED) {
    g.pot_v         = adc_to_volts(adc_read_channel(ADC_CH_POT));
    g.i_threshold_a = pot_to_threshold_a(g.pot_v);
  } else {
    g.pot_v = 0.0f; /* floating, ignored */
    /* g.i_threshold_a is set by <ith> serial command or boot default */
  }

  g.duty_frac = (float)g.duty_current / (float)PWM_WRAP;
  g.i_raw_a   = volts_to_current_a(g.so_v, g.duty_frac);
  g.i_filt_a  = (1.0f - IIR_ALPHA) * g.i_filt_a + IIR_ALPHA * g.i_raw_a;

  /* dI/dt ring buffer */
  g.i_hist[g.i_hist_idx] = g.i_filt_a;
  g.i_hist_idx            = (g.i_hist_idx + 1) % DI_DT_HISTORY;
}

/* =========================================================================
 *  CURRENT SLOPE
 * ========================================================================= */
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
int main(void) {
  /* 1. UART first so everything after is logged */
  uart_init_debug();
  sleep_ms(50);

  g.boot_time = get_absolute_time();

  printf("\n\n");
  printf("=========================================================\n");
  printf("  DRV8701 Screwdriver  -- verbose debug build\n");
  printf("  CMSIS-DAP / Picoprobe  115200 8N1  GP0(TX) GP1(RX)\n");
  printf("=========================================================\n");
  printf("  sys_clk        = %u Hz\n",   clock_get_hz(clk_sys));
  printf("  PWM            = 20 kHz  wrap=%u clkdiv=%.1f\n",
         PWM_WRAP, (double)PWM_CLKDIV);
  printf("  SO divider     = %.4f  (10k top + 20k btm)\n",
         (double)SO_DIVIDER_RATIO);
  printf("  R_sense        = %.0f mohm\n",  (double)(R_SENSE_OHM * 1000.0f));
  printf("  Amp gain       = %.0f V/V\n",   (double)DRV_AMP_GAIN);
  printf("  SO offset      = %.0f mV\n",    (double)(SO_OFFSET_V * 1000.0f));
  printf("  Pot connected  = %s\n",         POT_CONNECTED ? "YES" : "NO");
  printf("  I_thr default  = %.1f A\n",     (double)I_THRESHOLD_DEFAULT_A);
  printf("  I_thr range    = %.1f .. %.1f A\n",
         (double)I_THRESHOLD_MIN_A, (double)I_THRESHOLD_MAX_A);
  printf("  I_hard_limit   = %.1f A\n",     (double)I_HARD_LIMIT_A);
  printf("  Triggers       : CW=GP%u  CCW=GP%u  (active-LOW, internal pull-up)\n",
         PIN_BTN_CW, PIN_BTN_CCW);
  printf("  LED            : GP%u  (blink=running, solid=fault, off=idle)\n",
         PIN_LED);
  printf("  Send <help> for full status + command list\n");
  printf("=========================================================\n\n");

  /* 2. GPIOs */
  gpio_init_all();
  LOG("GPIO init done  (nSLEEP=0, bridge Hi-Z, LED off)");

  /* 3. Peripherals */
  pwm_init_motor();
  LOG("PWM init done  (slice=%u chan=%u @ 20 kHz)",
      pwm_gpio_to_slice_num(PIN_EN_PWM), pwm_gpio_to_channel(PIN_EN_PWM));
  adc_init_all();
  LOG("ADC init done  (SO=CH%u GP%u  POT=CH%u GP%u -- pot %s)",
      ADC_CH_SO, PIN_ADC_SO, ADC_CH_POT, PIN_ADC_POT,
      POT_CONNECTED ? "active" : "ignored");

  /* 4. Software state */
  memset(&g, 0, sizeof(g));
  g.state         = State::BOOT;
  g.dir           = Direction::CW;
  g.pwm_slice     = pwm_gpio_to_slice_num(PIN_EN_PWM);
  g.pwm_chan      = pwm_gpio_to_channel(PIN_EN_PWM);
  g.i_threshold_a = I_THRESHOLD_DEFAULT_A;
  g.boot_time     = get_absolute_time(); /* re-capture after memset */
  button_init(g.sw_cw,  PIN_BTN_CW);
  button_init(g.sw_ccw, PIN_BTN_CCW);
  g.last_log         = get_absolute_time();
  g.last_logged_duty = 0xFFFFu;

  LOG("Default Ith = %.2f A  (use <ith X.X> to change)", (double)g.i_threshold_a);

  /* 5. Watchdog */
  watchdog_enable(WATCHDOG_TIMEOUT_MS, true);
  LOG("Watchdog armed  (%u ms timeout)", WATCHDOG_TIMEOUT_MS);

  /* 6. nFAULT sanity check at boot */
  sleep_ms(10);
  if (gpio_get(PIN_NFAULT) == 0) {
    LOG("*** WARN *** nFAULT is LOW at boot! "
        "Check VM / pull-up / DRV8701 wiring (GP%u)", PIN_NFAULT);
  } else {
    LOG("nFAULT OK (HIGH) at boot  (GP%u = 1)", PIN_NFAULT);
  }

  /* 7. Check if any button is already pressed at boot (log the raw state) */
  LOG("Boot button state:  CW(GP%u)=%d  CCW(GP%u)=%d",
      PIN_BTN_CW,  gpio_get(PIN_BTN_CW),
      PIN_BTN_CCW, gpio_get(PIN_BTN_CCW));

  /* 8. Initial ADC snapshot */
  {
    float so_v  = adc_to_volts(adc_read_channel(ADC_CH_SO));
    float pot_v = adc_to_volts(adc_read_channel(ADC_CH_POT));
    LOG("Initial ADC:  SO=%.3fV (expect ~0V at rest)  "
        "POT=%.3fV %s",
        (double)so_v, (double)pot_v,
        POT_CONNECTED ? "" : "(pot disconnected -- reading ignored)");
  }

  /* 9. Enter IDLE */
  motor_sleep();
  enter_state(State::IDLE, "init done");
  LOG("Ready.  Press CW(GP%u) or CCW(GP%u) to run, or send serial commands.",
      PIN_BTN_CW, PIN_BTN_CCW);

  absolute_time_t next_tick = get_absolute_time();

  /* === Main control loop ============================================== */
  while (true) {
    watchdog_update();

    serial_process();
    update_inputs();
    state_machine_step();
    led_update();
    debug_log_periodic();

    next_tick = delayed_by_us(next_tick, LOOP_PERIOD_US);
    absolute_time_t now = get_absolute_time();
    if (absolute_time_diff_us(now, next_tick) > 0) {
      sleep_until(next_tick);
    } else {
      LOG("OVERRUN: loop body exceeded %u us", LOOP_PERIOD_US);
      next_tick = now;
    }
  }

  return 0;
}

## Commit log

2026-03-12 Added essentials, tentative PCB layout
    [Screw Driver.kicad_pcb, Screw Driver.kicad_sch]
2026-03-17 Some routing done
    [Screw Driver.kicad_pcb, Screw Driver.kicad_sch]
2026-03-18 Some more routing done
    [Screw Driver.kicad_pcb, Screw Driver.kicad_sch]
2026-03-22 Routing fully done
    [Screw Driver.kicad_pcb, Screw Driver.kicad_sch]
2026-04-01 Improved Layout
    [Screw Driver.kicad_pcb, Screw Driver.kicad_sch]
2026-04-03 Changed Driver
2026-04-03 Made Schematic for DRV
    [DRV8701-ESD.kicad_pcb, DRV8701-ESD.kicad_sch]
2026-04-04 Finalized few components
    [DRV8701-ESD.kicad_pcb, DRV8701-ESD.kicad_sch]
2026-04-07 Component Placement - Tentative
    [DRV8701-ESD.kicad_pcb]
2026-04-08 Added PMOS, Changed VREF to 3v3, Added 5->3v3 LDO, Placed components tentatively. Yet to review.
    [DRV8701-ESD.kicad_pcb, DRV8701-ESD.kicad_sch]
2026-04-08 Some layout changes
    [DRV8701-ESD.kicad_pcb]
2026-04-08 Some more stuff added
    [DRV8701-ESD.kicad_pcb, DRV8701-ESD.kicad_sch]
2026-04-08 Changes done after review
    [DRV8701-ESD.kicad_pcb, DRV8701-ESD.kicad_sch]
2026-04-09 Routing Done, yet to review
    [DRV8701-ESD.kicad_pcb, DRV8701-ESD.kicad_sch, QFN 24.STEP]
2026-04-10 Added SMD and THT Debug Connectors. Some small changes.
    [DRV8701-ESD.kicad_pcb, DRV8701-ESD.kicad_sch]
2026-04-10 Made improvements.
    [DRV8701-ESD.kicad_pcb, DRV8701-ESD.kicad_sch, QFN 24.STEP]
2026-04-11 Added pours, final changes
    [DRV8701-ESD.kicad_pcb, DRV8701-ESD.kicad_sch, QFN 24.STEP]
2026-04-15 Made some final changes, ordered.
    [.step, DRV8701-ESD.kicad_pcb, DRV8701-ESD.kicad_sch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]
2026-05-30 Working COde, final PCB files added.
    [.step, DRV8701-ESD.kicad_pcb, DRV8701-ESD.kicad_sch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]
